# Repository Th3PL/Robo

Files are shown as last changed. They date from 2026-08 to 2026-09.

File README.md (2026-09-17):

# 🤖 Carrinho-Robô SMARS — Bluetooth + desvio de obstáculos

**Project-based Maker Lab · Check Point 1 · FIAP**

| Integrante | RM |
|---|---|
| Fernanda Kaory Saito | RM551104 |
| João Pedro Borsato Cruz | RM550294 |
| Maria Fernanda Vieira de Camargo | RM97956 |
| Pedro Lucas de Andrade Nunes | RM550366 |
| Sofia Amorim Coutinho | RM552534 |

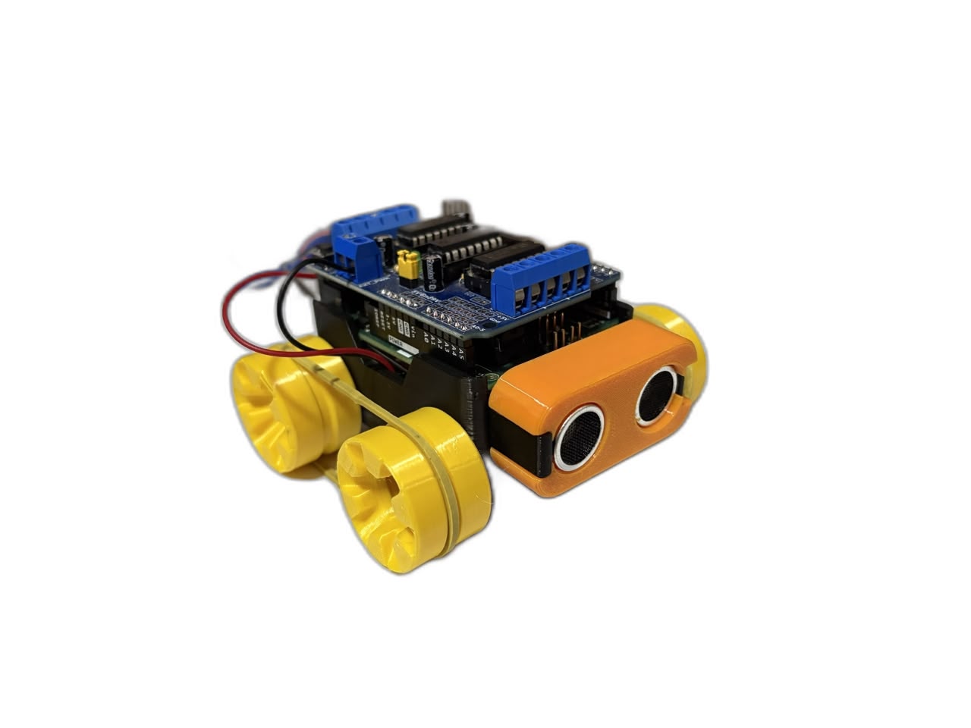
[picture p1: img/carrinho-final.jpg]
Carrinho finalizado


🎬 **Vídeo de funcionamento (controle remoto + sensor + modo autônomo):** https://youtu.be/DnCW8VLloSI

---

## Sumário

1. [Objetivo e descrição](#1-objetivo-e-descrição)
2. [Principais funcionalidades](#2-principais-funcionalidades)
3. [Organização do repositório](#3-organização-do-repositório)
4. [Linha do tempo do projeto](#4-linha-do-tempo-do-projeto)
5. [Requisitos, planejamento e evolução](#5-requisitos-planejamento-e-evolução)
6. [Projeto mecânico e fabricação](#6-projeto-mecânico-e-fabricação)
7. [Hardware e eletrônica](#7-hardware-e-eletrônica)
8. [Software](#8-software)
9. [Testes e resultados](#9-testes-e-resultados)
10. [Evidências finais e instruções de uso](#10-evidências-finais-e-instruções-de-uso)
11. [Custos](#11-custos)
12. [Créditos e licença](#12-créditos-e-licença)

---

## 1. Objetivo e descrição

Desenvolver um carrinho-robô funcional integrando projeto mecânico, fabricação digital, eletrônica,
programação e documentação. O robô é controlado pelo celular via **Bluetooth**, possui um **sensor
ultrassônico** que impede colisões e um **modo autônomo** em que anda sozinho desviando de obstáculos.

A estrutura é impressa em 3D a partir do projeto open-source **SMARS**, montada e adaptada pela equipe:
a proposta original com esteiras foi descartada após os testes e as **rodas foram redesenhadas** pela
equipe em quatro iterações até chegar a uma versão com canal para elástico, que resolveu a tração.

| | |
|---|---|
| **Microcontrolador** | Arduino Uno R3 |
| **Ponte H** | Shield L293D (empilhado no Uno) |
| **Motores** | 2× N20 com redução, 6 V, 500 rpm |
| **Sensor** | HC-SR04 (ultrassônico), na capa frontal |
| **Comunicação** | HC-05 (Bluetooth SPP) + app *Arduino Bluetooth RC Car* |
| **Alimentação** | Bateria 9 V no compartimento do chassi |
| **Estrutura** | Chassi SMARS impresso em PLA · rodas redesenhadas pela equipe |

---

## 2. Principais funcionalidades

- **Controle remoto Bluetooth**: frente, ré, esquerda, direita, diagonais, parar e **velocidade** pelo slider do app.
- **Segurança por sensor**: no modo manual, um obstáculo a menos de 20 cm **bloqueia o avanço** (ré e giros continuam liberados); liberou o caminho, o avanço volta.
- **Modo autônomo** (botão `X` do app): anda sozinho, desacelera ao se aproximar de obstáculos e, ao encontrar um, dá ré e **gira até o sensor ver caminho livre**; se ficar preso, faz manobra de fuga.
- **Leitura robusta do ultrassônico**: timeout, mediana de 3 leituras e tratamento de "sem eco".
- **Tração diferencial** com rodas motoras 1 mm maiores que as livres (contato garantido) e elástico na banda de rodagem.
- **Telemetria** pela USB (distância, modo, comandos) para depuração e calibração.

---

## 3. Organização do repositório

```
Robo/
├── README.md                      ← este documento
├── cad/
│   ├── README.md                  ← origem do chassi, evolução das rodas, como regenerar
│   ├── stl/robo_arduino.3mf       ← projeto de fatiamento completo (9 placas, Sovol SV07)
│   ├── stl/rodas/*.stl            ← rodas v1 (lisa), v2 (ranhurada) e v4 (canal p/ elástico — final)
│   └── scripts/                   ← remodel.js (gera as rodas), manifold_check.js, stl_render.js
├── hardware/
│   ├── conexoes.md                ← pinagem final, diagrama e alimentação
│   └── diagrama-componentes.*     ← diagrama da arquitetura PLANEJADA (L298N), mantido como histórico
├── software/
│   ├── smars_completo/            ← FIRMWARE FINAL: Bluetooth + segurança + modo autônomo
│   ├── smars_bluetooth/           ← só controle Bluetooth (didático)
│   ├── smars_desvio/              ← só desvio autônomo (didático)
│   └── historico/                 ← versões iniciais (v1) mantidas como registro
├── organizacao/                   ← MVP, MoSCoW, Backlog, Kanban (planejamento das aulas)
└── img/
    ├── carrinho-final.jpg · componentes.jpg · chassi-interno.jpg
    ├── previa.png · diagrama-blocos.png · diagrama-eletrico.png · tabela.png   (proposta inicial)
    ├── fabricacao/placa-1..9.png  ← placas de impressão
    └── rodas/                     ← renders de cada versão das rodas
```

---

## 4. Linha do tempo do projeto

| Data | Etapa | Evidência |
|---|---|---|
| **13/08** | Kickoff: repositório criado, definição dos requisitos, levantamento e medição dos componentes | commits `49098f2`, `54a73b1`; [img/tabela.png](img/tabela.png) |
| **18/08** | Proposta inicial: diagrama de blocos, diagrama elétrico (comando/potência) e prévia 3D do carrinho. Arquitetura planejada: Uno + L298N + 2× N20 + HC-SR04 + HC-05 + 7,4 V | commit `8a23aa2`; [previa](img/previa.png), [blocos](img/diagrama-blocos.png), [elétrico](img/diagrama-eletrico.png) |
| **27/08** | Planejamento: MVP, MoSCoW, backlog com 38 tarefas e kanban; projeção de custos | PR #1 `tarefa17-mvp`, commit `2977194`; [organizacao/](organizacao/) |
| **01/09** | Fabricação digital: escolha do chassi SMARS, fatiamento em 9 placas (Bambu Studio, perfil Sovol SV07); diagrama de componentes | commit `f2c2535`; [cad/stl/robo_arduino.3mf](cad/stl/robo_arduino.3mf), [img/fabricacao/](img/fabricacao/) |
| **01/09 – início de set.** | Impressão de todas as peças e montagem. **Decisões**: shield L293D no lugar da L298N; bateria 9 V no lugar de 7,4 V (compartimento do chassi) | [img/componentes.jpg](img/componentes.jpg), [img/chassi-interno.jpg](img/chassi-interno.jpg) |
| **11/09** | Primeiro teste de locomoção com **esteiras**: laço curto demais, a esteira pressionava as rodas e **travava o motor**. Tentativas: compensação XY dos furos no fatiador (0,065 → 0,115 mm), esticar cada elo 1,4 % (16 elos), lixar e lubrificar as juntas. Sem sucesso → **esteiras descartadas** | seção [Testes](#9-testes-e-resultados) |
| **15/09** | **Rodas v1 (lisas Ø32)** geradas por script a partir da roda original: dentes de engate removidos, encaixes internos preservados. **v2 ranhurada** (24 sulcos) para tração | [cad/README.md](cad/README.md), [img/rodas/](img/rodas/) |
| **16/09** | Problema: rodas motoras **girando em falso** (mesmo diâmetro das livres → perdiam contato). **v3**: motoras Ø33, livres Ø32 | `cad/stl/rodas/roda_motor_*.stl` |
| **17/09** | **v4 – canal para elástico** com parede em rampa de 45° (imprime sem suporte). Elástico nas motoras: **tração resolvida** ✅ | [img/rodas/v4-canal-render.png](img/rodas/v4-canal-render.png) |
| **17/09** | Firmware: desvio v1 → v2 (filtro, escaneio) → **v3** (gira até ver livre, fuga); Bluetooth v2 (velocidade, diagonais); **firmware unificado** com modo manual seguro + autônomo | [software/](software/) |
| **17/09** | Documentação final desta versão do repositório | este README |

---

## 5. Requisitos, planejamento e evolução

### 5.1 Requisitos (MVP)

Definidos em [organizacao/MVP.pdf](organizacao/MVP.pdf) e priorizados em [organizacao/MoSCoW .pdf](organizacao/MoSCoW%20.pdf):

| Requisito | Critério de aceite | Status |
|---|---|---|
| Arduino operacional | programa carregado e executando | ✅ |
| Ponte H controla os dois motores | frente, ré e curvas | ✅ (shield L293D) |
| Frente / ré / esquerda / direita / parar | movimentos executados pelo robô | ✅ |
| Bluetooth | celular envia comandos ao Arduino | ✅ |
| HC-SR04 mede distância | leitura correta em cm | ✅ (com filtro) |
| Segurança: obstáculo tem prioridade sobre o avanço | robô impede o avanço | ✅ |
| Alimentação por bateria | opera sem USB | ✅ (9 V) |
| *Should*: velocidade por PWM, distância configurável | slider do app; constantes no código | ✅ |
| *Could*: modo automático com desvio de obstáculos | robô navega sozinho | ✅ |
| *Should*: tratamento de perda do Bluetooth | estado seguro ao perder conexão | ⏳ backlog |

### 5.2 Proposta inicial e esboços

| Prévia 3D (18/08) | Diagrama de blocos planejado |
|---|---|
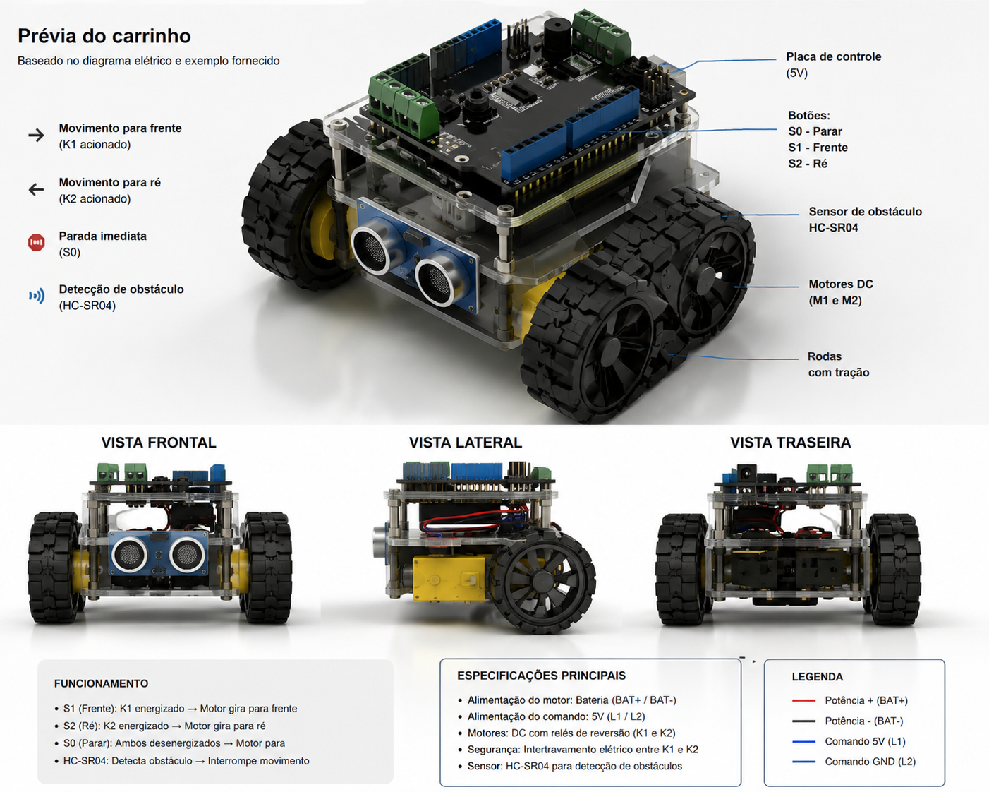
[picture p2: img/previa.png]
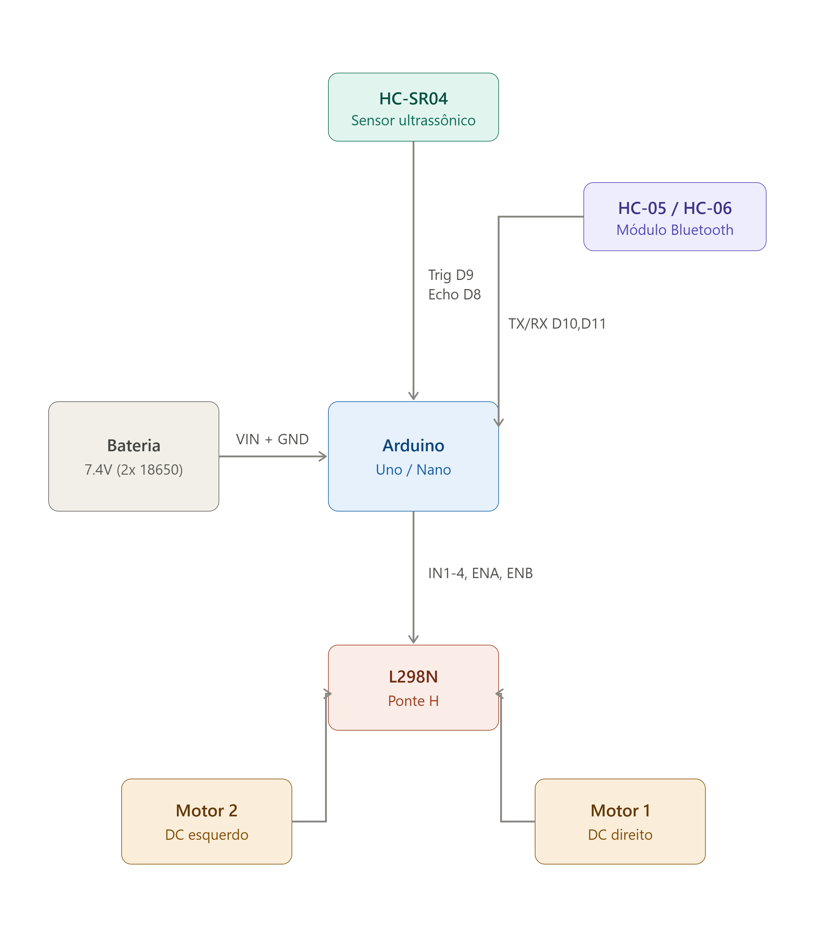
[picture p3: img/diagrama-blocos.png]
|  |  |

Diagrama elétrico da lógica de comando/potência (18/08): [img/diagrama-eletrico.png](img/diagrama-eletrico.png).
Dimensões medidas dos componentes para o projeto do chassi (13/08): [img/tabela.png](img/tabela.png).

### 5.3 Planejamento

- **MVP** — [organizacao/MVP.pdf](organizacao/MVP.pdf): quando o robô é "minimamente funcional" e quando está concluído.
- **MoSCoW** — [organizacao/MoSCoW .pdf](organizacao/MoSCoW%20.pdf): must / should / could / won't.
- **Backlog** — [organizacao/Backlog.md](organizacao/Backlog.md): 38 tarefas com responsável, dependência e critério de aceite.
- **Kanban** — [organizacao/Kanban.md](organizacao/Kanban.md): colunas, limites de WIP e sprints.

### 5.4 Decisões de projeto (planejado × construído)

| Item | Planejado (ago.) | Construído (set.) | Por quê |
|---|---|---|---|
| Ponte H | L298N avulsa, 6 fios de controle | **Shield L293D** empilhado no Uno | Encaixa direto no Uno e no chassi SMARS, elimina jumpers de controle, mais barato (R$ 11,90) |
| Alimentação | 2× 18650 (7,4 V) | **Bateria 9 V alcalina** | O chassi SMARS tem compartimento para 9 V; dispensa carregador/BMS; os 9 V compensam a queda de ~1,5 V do L293D |
| Locomoção | 2 rodas motoras + roda boba | **4 rodas: 2 motoras + 2 livres**, sem esteira | Esteira do SMARS travava o motor; rodas com elástico deram tração e permitem girar no lugar |
| Rodas | rodas do SMARS com dentes de esteira | **Rodas redesenhadas** (v4: lisas, Ø33/Ø32, canal p/ elástico) | Ver [linha do tempo](#4-linha-do-tempo-do-projeto) e [cad/README.md](cad/README.md) |
| Pinos do HC-SR04 | D8 / D9 | **A0 / A1** | D8 e D9 são usados pelo shield |
| Pinos do HC-05 | D10 / D11 | **D9 / D10** (conectores de servo do shield) | D11 é o PWM do motor M1 no shield |
| Sensor no software | só parada por obstáculo | Parada **+ desvio autônomo + fuga quando preso** | Evolução de item *could have* do MoSCoW |

### 5.5 Status final do backlog

| Tarefas | Status |
|---|---|
| T01–T10 componentes, layout, base, fixações | ✅ concluídas (chassi SMARS impresso; suportes de motor, bateria e sensor) |
| T11–T13 alimentação e ligação dos motores | ✅ (bateria 9 V → shield; motores em M1/M2) |
| T14–T20 testes dos motores e funções de movimento | ✅ |
| T21–T23 sensor conectado, leitura, parada por obstáculo | ✅ |
| T24–T26 Bluetooth e mapeamento de comandos | ✅ |
| T27 fail-safe de perda do Bluetooth | ⏳ não implementado |
| T28 calibração da distância | ✅ (constantes `DIST_PARAR`, `DIST_REDUZIR`, `DIST_LIVRE`) |
| T29–T30 movimentação integrada e detecção em movimento | ✅ |
| T31 organização dos cabos | 🔶 parcial |
| T32 autonomia da bateria | ⏳ não medida formalmente |
| T33–T34 percurso completo e correção de bugs | ✅ (ver [Testes](#9-testes-e-resultados)) |
| T35–T37 documentação de circuito, software e montagem | ✅ |
| T38 demonstração | 🎬 vídeo — link no topo |

---

## 6. Projeto mecânico e fabricação

### 6.1 Chassi

O chassi é o **SMARS** (Screwless Modular Assemblable Robotic System, de Kevin Thomas — projeto open-source
publicado no Thingiverse sob licença Creative Commons). Foi escolhido em 01/09 porque já prevê exatamente os
componentes do nosso planejamento: berços para motores N20, compartimento para bateria 9 V, encaixe do Arduino
Uno com shield e capa frontal para o HC-SR04. Toda a fabricação (fatiamento, impressão, pós-processamento e
montagem) foi feita pela equipe; a **adaptação mecânica** foi o redesenho completo das rodas.

**Fatiamento** — Bambu Studio 2.3, perfil Sovol SV07, bico 0,4 mm, camada 0,2 mm, PLA. Projeto completo em
[cad/stl/robo_arduino.3mf](cad/stl/robo_arduino.3mf), organizado em 9 placas:

| Placa 1 – esteiras | Placa 2 – chassi | Placa 3 – rodas originais |
|---|---|---|
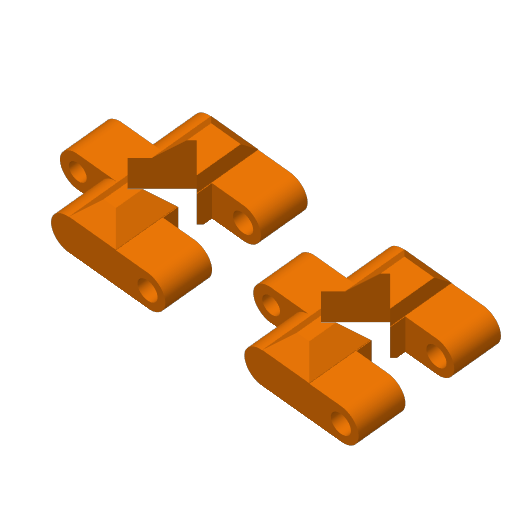
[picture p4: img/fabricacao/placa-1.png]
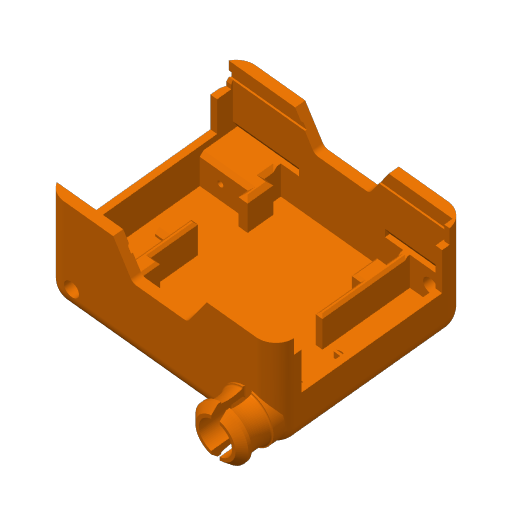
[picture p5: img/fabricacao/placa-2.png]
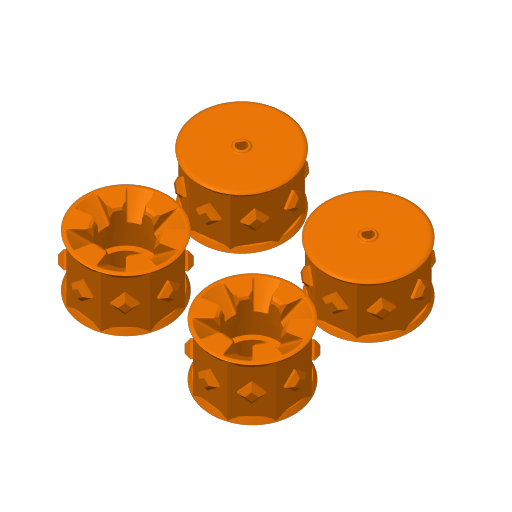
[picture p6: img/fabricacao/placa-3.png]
|  |  |  |
| **Placa 4 – suporte bateria 9 V** | **Placa 5 – suporte sensor IR (opcional)** | **Placa 6 – conector (opcional)** |
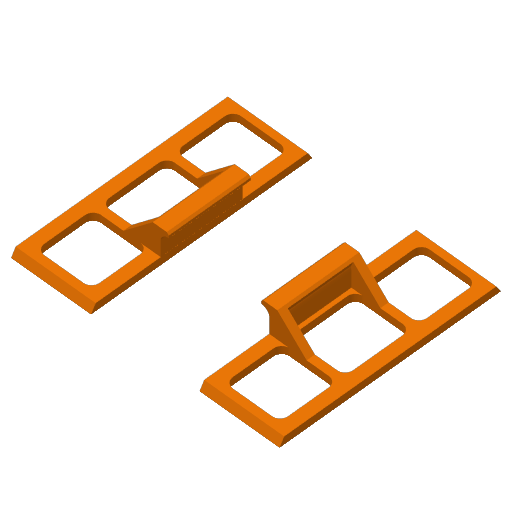
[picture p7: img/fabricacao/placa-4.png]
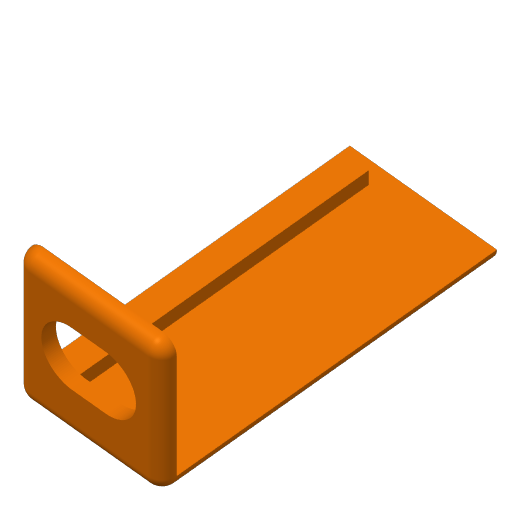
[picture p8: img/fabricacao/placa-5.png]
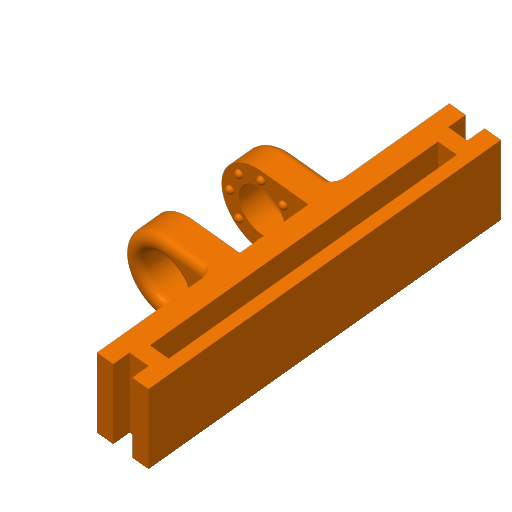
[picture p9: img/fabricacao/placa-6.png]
|  |  |  |
| **Placa 7 – capa HC-SR04 (base)** | **Placa 8 – capa HC-SR04 (a)** | **Placa 9 – capa HC-SR04 (b)** |
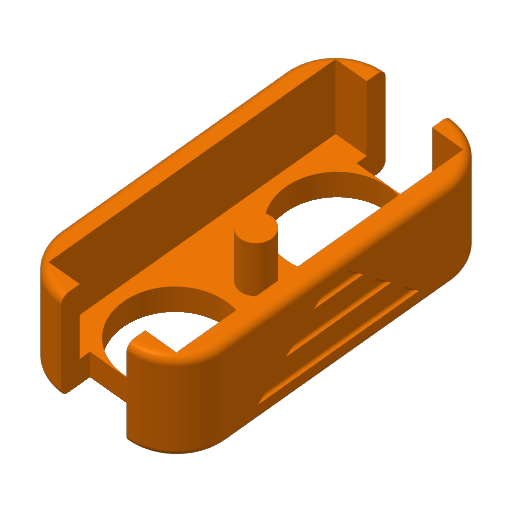
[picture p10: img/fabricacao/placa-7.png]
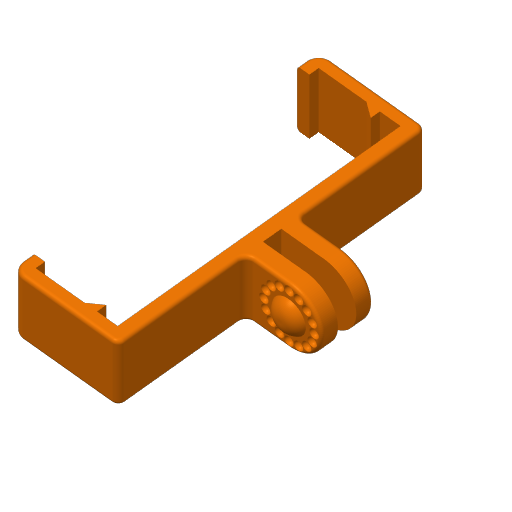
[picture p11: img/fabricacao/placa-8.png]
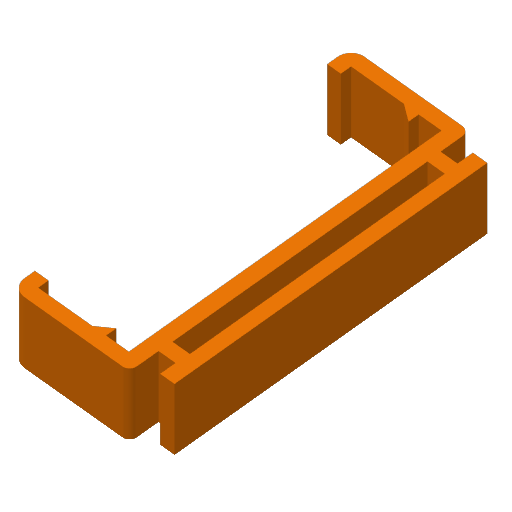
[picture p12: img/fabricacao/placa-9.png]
|  |  |  |

| Peças impressas antes da montagem | Chassi montado por baixo (motores N20 nos berços, bateria 9 V) |
|---|---|
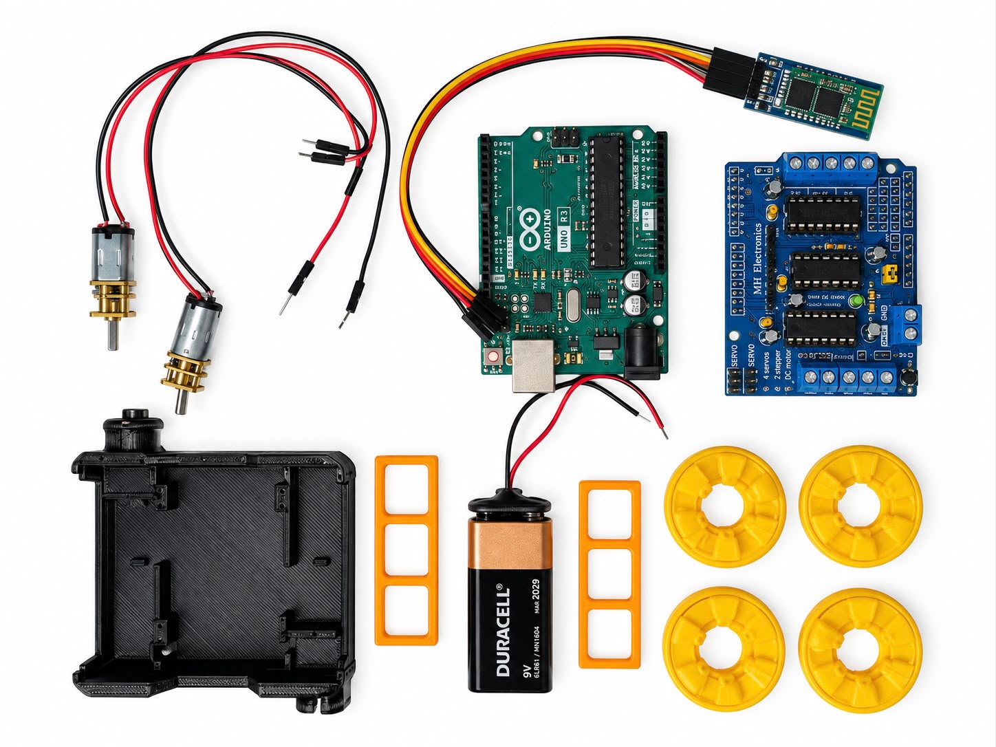
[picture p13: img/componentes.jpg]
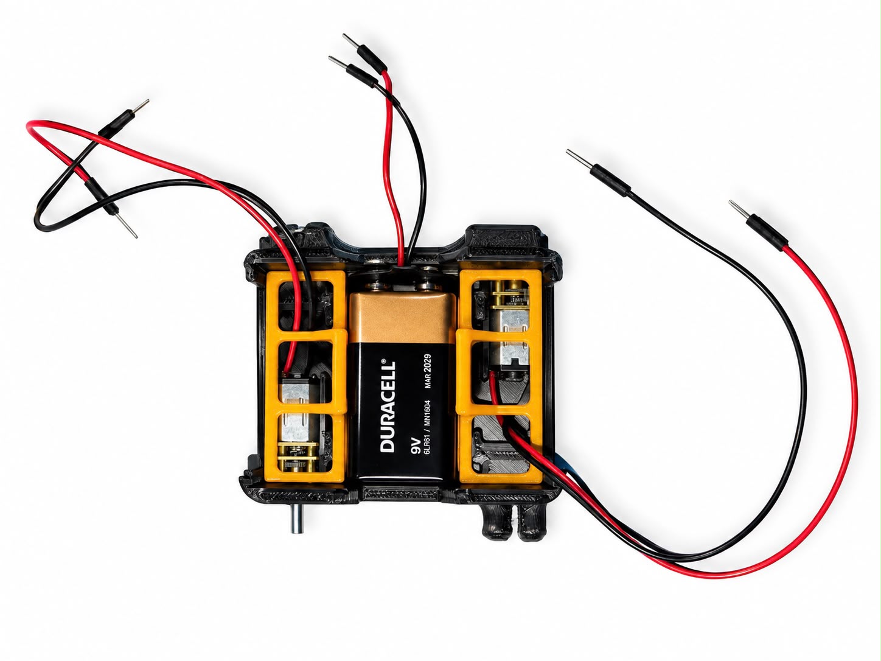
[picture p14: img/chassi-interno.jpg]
|  |  |

### 6.2 Rodas — quatro iterações

A roda original do SMARS tem 8 dentes piramidais que engatam nos losangos da esteira. Como a esteira foi
descartada, as rodas foram **regeneradas por script** ([cad/scripts/remodel.js](cad/scripts/remodel.js)) a
partir do STL original: a superfície externa é reconstruída (lisa, ranhurada ou com canal) enquanto o
**encaixe interno** (furo D do motor N20, cavidade de 6 lóbulos, furo passante da roda livre) é preservado.
Cada STL foi validado por um verificador de malha (0 arestas abertas, 0 não-manifold) antes de imprimir.

| v0 – original (dentes p/ esteira) | v1 – lisa Ø32 | v2 – ranhurada |
|---|---|---|
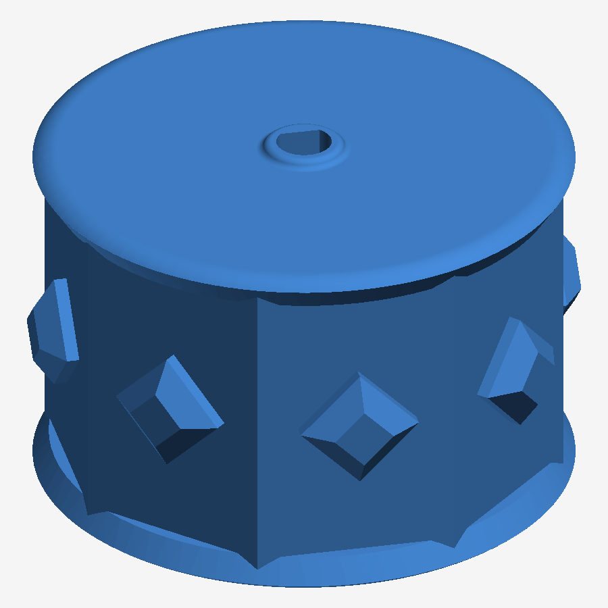
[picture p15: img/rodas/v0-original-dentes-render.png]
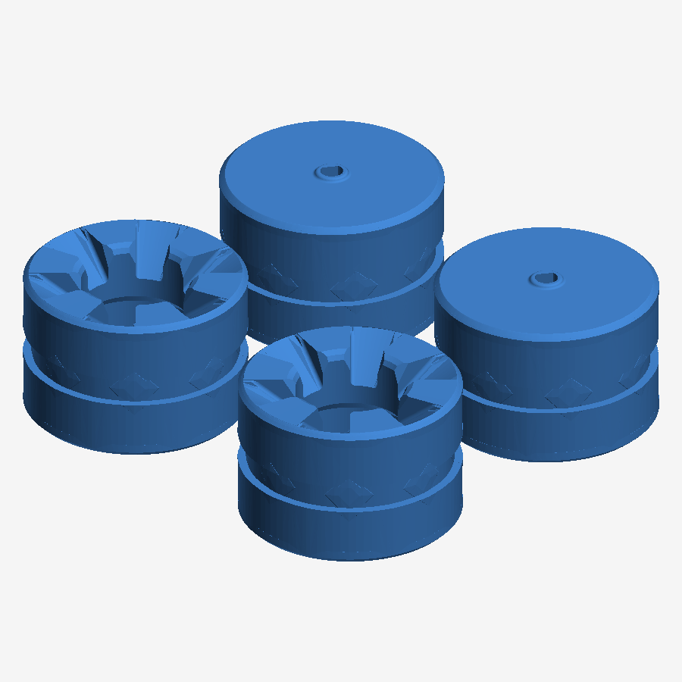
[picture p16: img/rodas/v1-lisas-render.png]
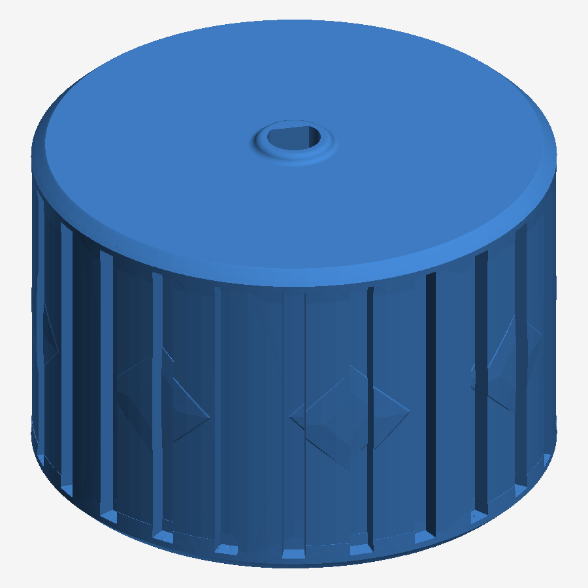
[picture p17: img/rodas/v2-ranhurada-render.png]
|  |  |  |
| **Elo da esteira descartada** | **v4 – canal para elástico (final)** | **v4 – perfil do canal** |
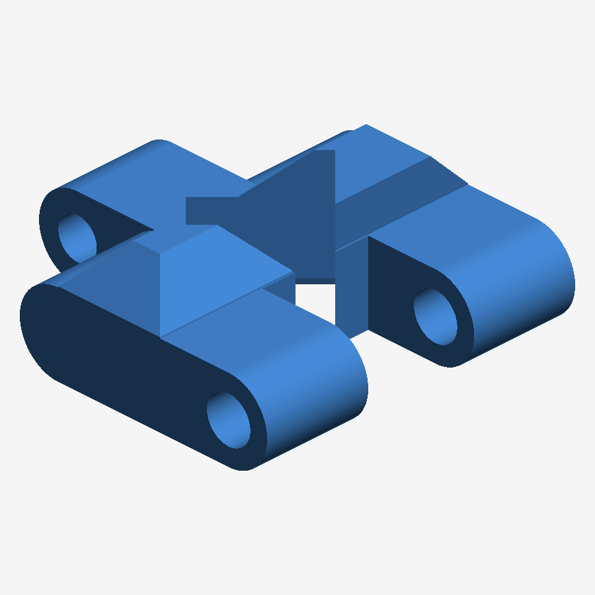
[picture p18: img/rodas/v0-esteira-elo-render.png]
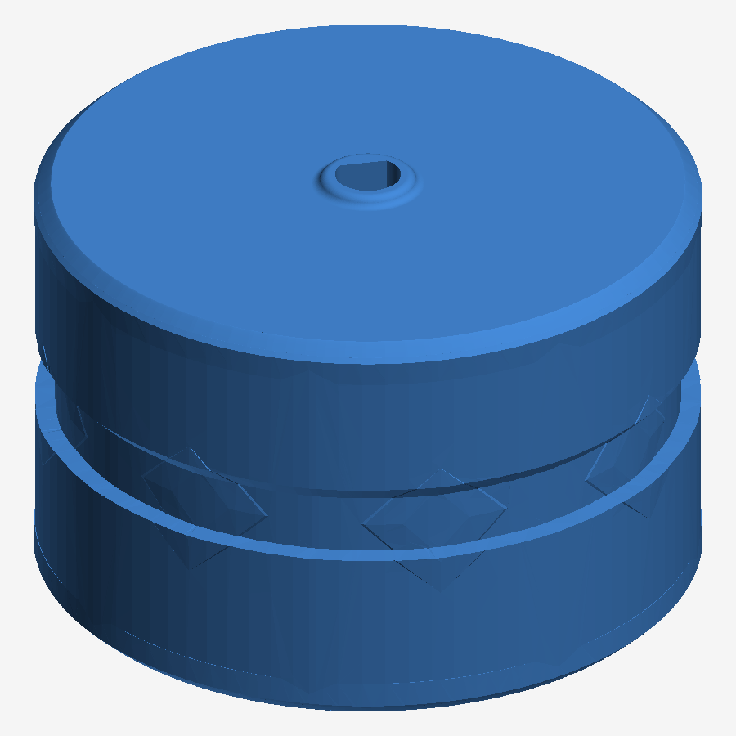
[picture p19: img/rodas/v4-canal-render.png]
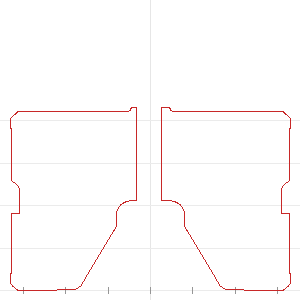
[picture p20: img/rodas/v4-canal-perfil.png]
|  |  |  |

Decisões de detalhe da v4:
- **Motora Ø33 × livre Ø32**: com 4 rodas rígidas, diâmetros iguais deixam uma roda no ar (como mesa de 4 pés). A motora 0,5 mm mais alta garante que o carrinho sempre apoie nas rodas de tração.
- **Canal** com fundo plano de 3 mm, 1 mm de profundidade, parede inferior reta e **parede superior em rampa de 45°**: imprime deitado sem suporte.
- **Elástico só nas motoras**: as rodas livres precisam deslizar de lado para o carrinho girar no lugar.
- Chanfros de 0,8 mm nas bordas; residual dos dentes reduzido a < 0,1 mm (abaixo da resolução do bico).

Tabela completa das versões, arquivos e como regenerar: [cad/README.md](cad/README.md).

### 6.3 Carenagem e acabamento

- **Capa frontal do sensor** (peças `ultrasonic_1`, `ultrasonic_2a`, `ultrasonic_2b` — placas 7 a 9), impressa em laranja: protege e posiciona o HC-SR04 voltado para a frente, com os dois transdutores expostos.
- **Suportes internos** da bateria (laranja) e dos motores integrados ao chassi; bateria e motores ficam totalmente encapsulados, com o shield acessível por cima para programação e troca de bateria.
- **Acesso aos componentes**: a parte superior (Uno + shield) fica aberta, o que permite programar pelo USB, trocar a bateria e mexer nos bornes sem desmontar nada. Uma tampa superior encaixável está prevista como melhoria (backlog).

---

## 7. Hardware e eletrônica

### 7.1 Lista de componentes

| Componente | Qtd | Função |
|---|---|---|
| Arduino Uno R3 | 1 | Microcontrolador: lógica, leitura do sensor, comunicação |
| Shield de motores L293D (MH Electronics, compatível Adafruit v1) | 1 | Ponte H de 4 canais (usamos M1 e M2) e distribuição de energia |
| Motor N20 com redução, 6 V, 500 rpm | 2 | Tração das rodas motoras |
| Sensor ultrassônico HC-SR04 | 1 | Distância 2–400 cm, detecção de obstáculos |
| Módulo Bluetooth HC-05 | 1 | Recebe comandos do celular (SPP, 9600 bps) |
| Bateria 9 V alcalina (6LR61) | 1 | Alimenta shield, motores e Uno |
| Chassi SMARS + suportes + capa do sensor (PLA) | — | Estrutura |
| Rodas redesenhadas v4 (PLA) | 4 | 2 motoras Ø33, 2 livres Ø32 |
| Elástico de dinheiro | 2 | Banda de rodagem das motoras (2 voltas cada) |
| Jumpers macho-macho e macho-fêmea | ~10 | Sensor, Bluetooth, bateria |

### 7.2 Diagrama de conexões

```mermaid
flowchart LR
    APP["Celular<br/>app Bluetooth RC Car"]
    BT["HC-05"]
    US["HC-SR04"]
    BAT["Bateria 9 V"]
    subgraph UNO["Arduino Uno R3 + shield L293D"]
        FW["Firmware"]
        H["Ponte H L293D"]
        FW -- "sentido + PWM" --> H
    end
    ME["Motor N20 esq."]
    MD["Motor N20 dir."]
    APP <-- "Bluetooth" --> BT
    BT <-- "D9 RX / D10 TX" --> FW
    US -- "TRIG A0 / ECHO A1" --> FW
    H -- "M1" --> ME
    H -- "M2" --> MD
    BAT -- "EXT_PWR" --> UNO
```

Tabela de ligações pino a pino, pinos reservados pelo shield e notas de alimentação:
**[hardware/conexoes.md](hardware/conexoes.md)**. O diagrama da arquitetura planejada (L298N) está em
[hardware/diagrama-componentes.png](hardware/diagrama-componentes.png).

### 7.3 Alimentação

Bateria 9 V no borne EXT_PWR do shield, jumper PWR instalado (o shield alimenta o Uno pelo Vin). O L293D
derruba ~1,5 V, então os motores recebem ~7,5 V. Com uma fonte menor (4 pilhas AA, 6 V) os motores ficariam
com ~4,5 V — insuficiente para vencer o atrito lateral das rodas livres nos giros no lugar.

### 7.4 Fotos da montagem

[img/componentes.jpg](img/componentes.jpg) · [img/chassi-interno.jpg](img/chassi-interno.jpg) · [img/carrinho-final.jpg](img/carrinho-final.jpg)

---

## 8. Software

### 8.1 Sketches

| Pasta | Uso | Estado |
|---|---|---|
| [`software/smars_completo/`](software/smars_completo/smars_completo.ino) | **Firmware final** — controle Bluetooth com segurança por sensor + modo autônomo, em um único upload | ✅ usar este |
| [`software/smars_bluetooth/`](software/smars_bluetooth/smars_bluetooth.ino) | Só controle Bluetooth (versão didática, sem sensor) | ✅ |
| [`software/smars_desvio/`](software/smars_desvio/smars_desvio.ino) | Só navegação autônoma (versão didática) | ✅ |
| [`software/historico/`](software/historico/) | Versões iniciais v1, com os problemas anotados no cabeçalho | histórico |

Compilação: Arduino IDE 2.x, placa **Arduino Uno**, biblioteca **Adafruit Motor Shield library (v1)**
(`AFMotor.h`). Os três sketches compilam sem avisos (≈ 6,4 kB de flash, 338 B de RAM no completo).

### 8.2 Como o programa funciona (`smars_completo`)

**Controle dos motores.** A biblioteca `AFMotor` comanda o shield: o sentido de cada canal passa por um
registrador 74HC595 e a velocidade pelos pinos PWM D11 (M1) e D3 (M2). A função `aplicar(velE, velD, dirE, dirD)`
centraliza tudo; `VEL_MAX_E/D` permitem compensar um motor mais forte para o carrinho andar reto. Curvas são
feitas por **tração diferencial**: giro no lugar (uma roda para frente, outra para trás) e diagonais com a roda
de dentro a 35 %.

**Comunicação sem fio.** O HC-05 conversa com o Uno por `SoftwareSerial` nos pinos D9/D10 a 9600 bps. O app
*Arduino Bluetooth RC Car* envia um caractere por botão:

| Caractere | Ação | | Caractere | Ação |
|---|---|---|---|---|
| `F` `B` | frente / ré | | `G` `I` | frente-esquerda / frente-direita |
| `L` `R` | gira esquerda / direita | | `H` `J` | ré-esquerda / ré-direita |
| `S` | parar (sai do autônomo) | | `0`–`9`, `q` | velocidade 10 %…100 % |
| `X` | **liga modo autônomo** | | `x` | desliga modo autônomo |

O último comando fica guardado e é reaplicado a cada volta do `loop()`, o que permite o bloqueio de segurança
descrito abaixo sem perder o comando do usuário.

**Sensor ultrassônico.** `lerCrua()` dispara o TRIG (10 µs) e mede o ECHO com `pulseIn` **com timeout de
25 ms** (sem eco = 400 cm, "livre" — a versão inicial devolvia 0 e o robô dava ré sem motivo). Um ping a
cada 60 ms e a **mediana das 3 últimas leituras** eliminam picos falsos sem travar o loop.

**Segurança (modo manual).** Se o último comando é de avanço (`F`, `G`, `I`) e a distância ≤ `DIST_PARAR`
(20 cm), os motores param; ré e giros continuam liberados. Quando o caminho libera, o avanço é retomado. Isso
implementa o requisito do MVP "obstáculo tem prioridade sobre o comando de avanço".

**Modo autônomo.** `passoAutonomo()` anda a `VEL_CRUZEIRO` e desacelera linearmente entre 45 e 20 cm. Ao
detectar obstáculo, `desviar()`: dá ré → **gira até o sensor ver ≥ 40 cm em 3 leituras seguidas** (+ margem)
→ segue. Se não abrir em 2,5 s: ré em arco para o outro lado e tenta o outro lado; se ainda não abrir:
meia-volta. Batidas seguidas mantêm o mesmo lado (a parede está do lado oposto); 3 desvios em 6 s = preso →
ré em arco longa e troca de lado. Girar "até ver livre" (em vez de girar por tempo fixo) foi a mudança que
resolveu o robô ficar oscilando frente-ré diante de paredes.

**Calibração.** Todas as constantes estão no topo do sketch: distâncias (`DIST_*`), velocidades (`VEL_*`),
tempos de manobra (`T_*`) e compensação por motor (`VEL_MAX_E/D`). O monitor serial (9600 bps) mostra o modo,
a distância e cada decisão de manobra.

### 8.3 Evolução do software

| Versão | Problema encontrado | Correção |
|---|---|---|
| v1 desvio ([historico](software/historico/v1_desvio_obstaculo.ino)) | `pulseIn` sem timeout → leituras 0 cm → ré aleatória; `int` estourava; reagia só a 7 cm; virava 500 ms às cegas | — |
| v2 desvio | filtro de mediana, reação a 20 cm, escaneio girando 45° para cada lado por tempo fixo | Ainda travava em paredes: quando o giro cronometrado ficava curto, media a mesma parede dos dois lados |
| **v3 desvio** ([smars_desvio](software/smars_desvio/smars_desvio.ino)) | — | Gira **até o sensor ver livre**, ré em arco, meia-volta, detecção de "preso", memória de lado |
| v1 Bluetooth ([historico](software/historico/v1_bluetooth.ino)) | `read()` sem `available()`; velocidade fixa; `J` tratado como parar | — |
| **v2 Bluetooth** ([smars_bluetooth](software/smars_bluetooth/smars_bluetooth.ino)) | — | slider de velocidade, diagonais, compensação por motor, 255 |
| **Unificado** ([smars_completo](software/smars_completo/smars_completo.ino)) | dois uploads diferentes para demonstrar sensor e Bluetooth | manual seguro + autônomo no mesmo firmware, alternado pelo app |

---

## 9. Testes e resultados

| # | Teste | Resultado | Problema / correção |
|---|---|---|---|
| 1 | Motores individuais (frente/ré) pelo shield | ✅ | — |
| 2 | Comandos Bluetooth F/B/L/R/S pelo app | ✅ | — |
| 3 | Locomoção com **esteiras** | ❌ | Laço curto: esteira pressionava as rodas e travava o motor. Tentativas: compensação de furos no fatiador +0,05 mm, elos esticados 1,4 %, lixa e lubrificação → **esteiras descartadas** |
| 4 | Rodas v1 lisas | ❌ | Rodam, mas PLA liso patina no piso |
| 5 | Rodas v2 ranhuradas (Ø32 = Ø32) | ❌ | Motoras giravam em falso: com diâmetros iguais perdiam o contato com o chão |
| 6 | Rodas v3 (motora Ø33 > livre Ø32) | 🔶 | Contato garantido; ainda faltava atrito em piso liso |
| 7 | Rodas v4 + elástico nas motoras | ✅ | **Tração resolvida**; carrinho anda e gira no lugar |
| 8 | Força dos motores | ✅ | Software já no máximo (`setSpeed(255)`); a força é definida pela tensão no shield (9 V) — ver [hardware/conexoes.md](hardware/conexoes.md) |
| 9 | Sensor: leituras com `pulseIn` sem timeout | ❌ | Valores 0 cm → ré aleatória. Corrigido com timeout + mediana |
| 10 | Desvio v2 diante de parede | ❌ | Oscilava frente-ré (giro cronometrado insuficiente) |
| 11 | Desvio v3 / firmware unificado | 🔄 | Gira até ver caminho livre; validação final registrada no vídeo |
| 12 | Bloqueio de avanço no modo manual | 🔄 | Obstáculo a < 20 cm para o carrinho; validação no vídeo |
| 13 | Autonomia da bateria | ⏳ | Não medida formalmente |

**Resultado final:** carrinho funcional, controlado pelo celular, com bloqueio de colisão e modo autônomo;
estrutura impressa em 3D com rodas redesenhadas pela equipe após o descarte das esteiras.

---

## 10. Evidências finais e instruções de uso

- **Foto do carrinho finalizado:** [img/carrinho-final.jpg](img/carrinho-final.jpg)
- **Vídeo (controle remoto, sensor e modo autônomo):** https://youtu.be/DnCW8VLloSI

### Como usar

1. Coloque a bateria 9 V no compartimento e conecte-a ao borne EXT_PWR do shield. O LED do HC-05 pisca rápido (aguardando pareamento).
2. No celular, pareie com o **HC-05** (PIN `1234` ou `0000`).
3. Abra o app **Arduino Bluetooth RC Car** (Android) → ícone de engrenagem → *Connect to car* → HC-05.
4. Setas: frente, ré, esquerda, direita e diagonais. Slider: velocidade. Ao soltar o botão o carrinho para.
5. Com um obstáculo a menos de 20 cm o avanço é bloqueado automaticamente; ré e giros continuam funcionando.
6. Botão extra **X** (ligado) → **modo autônomo**; **X** (desligado), qualquer seta ou *stop* → volta ao manual.
7. Para reprogramar: retire o jumper PWR do shield (ou a bateria), conecte o USB, grave `software/smars_completo` com a IDE Arduino (placa *Arduino Uno*, biblioteca *Adafruit Motor Shield library*).

Calibração recomendada no piso da demonstração: `VEL_MAX_E/D` (andar reto) e `T_MEIA_VOLTA_MS` (tempo de 180°).

---

## 11. Custos

| Componente | Qtd | Unitário | Total |
|---|---|---|---|
| Motor N20 500 rpm | 2 | R$ 20,40 | R$ 40,80 |
| Arduino Uno R3 | 1 | R$ 100,07 | R$ 100,07 |
| Módulo Bluetooth HC-05 | 1 | R$ 12,90 | R$ 12,90 |
| Shield ponte H L293D | 1 | R$ 11,90 | R$ 11,90 |
| Sensor HC-SR04 | 1 | R$ 15,00 | R$ 15,00 |
| Bateria 9 V | 1 | R$ 35,00 | R$ 35,00 |
| Cabos e jumpers | — | — | R$ 5,00 |
| Filamento PLA (~150 g) | — | — | R$ 10,00 |
| Elásticos | 2 | — | R$ 0,00 |
| **Total** | | | **R$ 230,67** |

---

## 12. Créditos e licença

- Chassi, suportes e capa do sensor: **SMARS** — Kevin Thomas, Thingiverse, licença Creative Commons (uso não comercial, atribuição).
- Rodas v1–v4, scripts de geração/validação, firmware e documentação: equipe do projeto.
- Biblioteca `AFMotor`: Adafruit Motor Shield library v1 (BSD).
- App de controle: *Arduino Bluetooth RC Car* (Android).

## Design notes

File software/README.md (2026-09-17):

# Software

| Pasta | Conteúdo |
|---|---|
| `smars_completo/` | **Firmware final** — controle Bluetooth com bloqueio de avanço por obstáculo + modo autônomo (`X` liga / `x` desliga) |
| `smars_bluetooth/` | Só controle Bluetooth (versão didática) |
| `smars_desvio/` | Só navegação autônoma com desvio de obstáculos (versão didática, v3) |
| `historico/` | Versões iniciais (v1) do Bluetooth e do desvio, com os problemas anotados no cabeçalho |

## Compilar e gravar

1. Arduino IDE 2.x → *Library Manager* → instalar **Adafruit Motor Shield library** (v1, `AFMotor.h`).
2. Placa: **Arduino Uno**. Abra a pasta do sketch (ex.: `smars_completo/smars_completo.ino`).
3. Antes de conectar o USB, retire o jumper PWR do shield ou a bateria.
4. Upload. Monitor serial a **9600 bps** (`smars_completo`, `smars_bluetooth`) ou **115200** (`smars_desvio`).

Os três sketches compilam sem erros nem avisos (`arduino-cli compile --fqbn arduino:avr:uno --warnings all`).

## Constantes de calibração (topo de cada sketch)

| Constante | Padrão | O que faz |
|---|---|---|
| `VEL_MAX_E`, `VEL_MAX_D` | 255 | Teto de cada motor; abaixe o mais forte se o carrinho puxa para um lado |
| `DIST_PARAR` | 20 cm | Obstáculo: bloqueia avanço (manual) / desvia (autônomo) |
| `DIST_REDUZIR` | 45 cm | Início da desaceleração no autônomo |
| `DIST_LIVRE` | 40 cm | Distância para considerar uma direção livre ao girar |
| `T_MEIA_VOLTA_MS` | 1200 ms | Tempo de giro de ~180° (último recurso) — calibrar no piso |
| `VEL_CRUZEIRO`, `VEL_MINIMA` | 220, 130 | Velocidades do modo autônomo |

A explicação completa do funcionamento está no README principal, seção 8.

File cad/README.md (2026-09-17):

# CAD e fabricação

## Origem do chassi

O chassi é baseado no projeto open-source **SMARS** (Screwless Modular Assemblable Robotic System), de
Kevin Thomas, publicado no Thingiverse sob licença Creative Commons. Escolhemos o SMARS porque o conjunto
já prevê o berço dos motores N20, o compartimento da bateria 9 V e a capa do sensor HC-SR04 — exatamente
os componentes definidos no nosso planejamento. Todas as peças foram fatiadas e impressas pela equipe;
as **rodas foram redesenhadas** pela equipe (ver abaixo), pois a proposta original com esteiras foi descartada.

## Arquivos

| Arquivo | O que é |
|---|---|
| `stl/robo_arduino.3mf` | Projeto de fatiamento completo (Bambu Studio 2.3, perfil Sovol SV07, camada 0,2 mm) com **9 placas**: esteiras, chassi, rodas originais, suporte da bateria 9 V, suporte de sensor IR, conector, capa do HC-SR04 (3 peças) |
| `stl/rodas/roda_motor_canal.stl` | **Versão final** – roda motora Ø33 mm com canal para elástico, autossustentável |
| `stl/rodas/roda_livre_canal.stl` | Versão final – roda livre Ø32 mm com canal |
| `stl/rodas/roda_motor_lisa.stl`, `roda_livre_lisa.stl` | v1/v3 – rodas lisas |
| `stl/rodas/roda_motor_ranhurada.stl`, `roda_livre_ranhurada.stl` | v2 – 24 ranhuras transversais |
| `scripts/remodel.js` | Script (Node.js, sem dependências) que gera as rodas a partir da roda original do SMARS: remove os dentes de engate da esteira e reconstrói a banda de rodagem (lisa / ranhurada / com canal) preservando o encaixe interno do motor e do eixo |
| `scripts/manifold_check.js` | Verificador de malha (arestas abertas / não-manifold) usado para validar cada STL antes de imprimir |
| `scripts/stl_render.js`, `scripts/split_wheels.js` | Render PNG dos STLs e separação das rodas em arquivos individuais |

Placas de impressão (miniaturas geradas pelo fatiador): `../img/fabricacao/placa-1.png` … `placa-9.png`.

## Evolução das rodas

| Versão | Arquivo | Diâmetro motora / livre | Resultado |
|---|---|---|---|
| v0 – original SMARS | no 3MF (`master_wheel`, `slave_wheel_SL`) | Ø32,7 com 8 dentes | Só funciona com esteira. A esteira travava o motor → descartada |
| v1 – lisa | `roda_*_lisa.stl` | Ø32 / Ø32 | Roda livre, mas PLA liso patina no piso |
| v2 – ranhurada | `roda_*_ranhurada.stl` | Ø32 / Ø32 | 24 ranhuras; ainda girava em falso: com diâmetros iguais as motoras ficavam sem contato com o chão |
| v3 – motora maior | (aplicado a v1 e v2; arquivos do repo já estão assim) | **Ø33 / Ø32** | Motora 0,5 mm mais alta garante contato sempre; faltava atrito |
| **v4 – canal para elástico** | `roda_*_canal.stl` | Ø33 / Ø32 (+ elástico) | **Final.** Elástico de dinheiro (2 voltas) nas motoras; tração resolvida |

Detalhes de cada decisão estão na linha do tempo do README principal.

## Como regenerar as rodas

```bash
node scripts/remodel.js roda.stl rodas_canal.stl canal        # variantes: (vazio)=lisa | ranhura | canal
node scripts/split_wheels.js rodas_canal.stl roda_motor_canal.stl roda_livre_canal.stl
node scripts/manifold_check.js roda_motor_canal.stl
```

`roda.stl` é a exportação das 4 rodas originais do 3MF (placa 3). Parâmetros (diâmetros, profundidade do
canal, número de ranhuras) estão no topo de `remodel.js`.

## Impressão

- Impressora Sovol SV07, bico 0,4 mm, camada 0,2 mm, PLA.
- Rodas: imprimir **deitadas, como o arquivo abre** (cavidade do motor para baixo). O canal do elástico tem a
  parede superior em rampa de 45° justamente para não precisar de suporte nessa orientação.
- Elástico: só nas rodas motoras. As rodas livres precisam deslizar de lado para o carrinho girar no lugar.

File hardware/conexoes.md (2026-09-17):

# Conexões elétricas — versão final

Arquitetura construída: Arduino Uno R3 + shield de motores L293D (empilhado no Uno) + 2 motores N20 +
HC-SR04 + HC-05 + bateria 9 V. O shield é a ponte H e também distribui a alimentação: a bateria entra no
borne **EXT_PWR** do shield e o Uno é alimentado pelo próprio shield (jumper PWR instalado).

> Esta é a arquitetura final. O planejamento inicial (`diagrama-componentes.*`, `img/diagrama-blocos.png`)
> previa ponte H L298N avulsa e bateria de 7,4 V; ver "Decisões de projeto" no README.

## Diagrama

```mermaid
flowchart LR
    APP["Celular<br/>app Bluetooth RC Car"]
    BT["HC-05<br/>Bluetooth SPP"]
    US["HC-SR04<br/>ultrassônico"]
    BAT["Bateria 9 V<br/>(6LR61)"]

    subgraph UNO["Arduino Uno R3 + shield L293D"]
        FW["Firmware<br/>software/smars_completo"]
        H["Ponte H L293D<br/>canais M1 e M2"]
        FW -- "PWM + sentido<br/>(74HC595 + D3/D11)" --> H
    end

    ME["Motor N20<br/>esquerdo"]
    MD["Motor N20<br/>direito"]

    APP <-- "2,4 GHz" --> BT
    BT <-- "UART 9600 bps<br/>D9 (RX) / D10 (TX)" --> FW
    US -- "TRIG A0 · ECHO A1" --> FW
    H -- "M1" --> ME
    H -- "M2" --> MD
    BAT -- "EXT_PWR (+/−)" --> UNO
```

## Tabela de ligações

| De | Para | Observação |
|---|---|---|
| Bateria 9 V (+) | Shield **EXT_PWR +** | Jumper **PWR** instalado: o shield alimenta o Uno pelo Vin |
| Bateria 9 V (−) | Shield **EXT_PWR −** (GND) | GND comum de todo o sistema |
| Motor N20 esquerdo | Shield borne **M1** | Inverter os dois fios se o motor girar ao contrário |
| Motor N20 direito | Shield borne **M2** | idem |
| HC-SR04 VCC | 5 V do shield | |
| HC-SR04 GND | GND | |
| HC-SR04 TRIG | **A0** | pinos analógicos usados como digitais (livres no shield) |
| HC-SR04 ECHO | **A1** | |
| HC-05 VCC | 5 V (pino central do conector de servo) | |
| HC-05 GND | GND (conector de servo) | |
| HC-05 TXD | **D9** (sinal do conector SERVO_2) | `SoftwareSerial bt(9, 10)` → RX do Arduino |
| HC-05 RXD | **D10** (sinal do conector SERVO_1) | TX do Arduino |

## Pinos consumidos pelo shield L293D (não usar para outra coisa)

| Pino | Função no shield |
|---|---|
| D3, D11 | PWM dos canais M2 e M1 |
| D4, D7, D8, D12 | registrador 74HC595 (sentido dos motores) |
| D5, D6 | PWM dos canais M3/M4 (não usados) |
| D9, D10 | conectores de servo — reaproveitados para o HC-05 |
| D0, D1 | serial USB (upload e monitor) |

Livres: **A0–A5** (por isso o HC-SR04 está em A0/A1) e D2, D13.

## Alimentação

- Tensão nos motores = 9 V − queda do L293D (~1,4 a 2 V) ≈ **7 a 7,5 V**. Os N20 usados são de 6 V;
  em uso intermitente e com carga leve funcionam bem nessa tensão.
- O Uno recebe 9 V no Vin pelo jumper PWR e regula para 5 V internamente.
- Nunca alimentar o shield pelo USB e pela bateria ao mesmo tempo com o jumper PWR instalado durante testes
  de motor: para programar com a bateria ligada, retire o jumper.

## Fotos da montagem

- `../img/componentes.jpg` — todos os componentes antes da montagem
- `../img/chassi-interno.jpg` — motores N20 nos berços, bateria 9 V central e cabos passando pelo chassi
- `../img/carrinho-final.jpg` — montagem final com shield empilhado e capa do sensor

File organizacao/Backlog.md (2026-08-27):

# Backlog do Projeto – Robô Móvel

## Papéis considerados
Como os nomes da equipe não foram informados, foram definidos quatro responsáveis genéricos:

- **Integrante A:** Software / Arduino
- **Integrante B:** Eletrônica
- **Integrante C:** Mecânica / Estrutura
- **Integrante D:** Testes / Documentação

## Backlog

| ID | Tarefa | Responsável | Prioridade | Dependência | Critério de aceite |
|---|---|---|---|---|---|
| T01 | Validar componentes disponíveis | Todos | Alta | — | Componentes conferidos |
| T02 | Definir arquitetura elétrica definitiva | B | Alta | T01 | Diagrama final aprovado |
| T03 | Definir posição dos componentes | C | Alta | T01 | Layout físico definido |
| T04 | Construir base do carrinho | C | Alta | T03 | Estrutura montada |
| T05 | Fixar motores | C | Alta | T04 | Motores firmes e alinhados |
| T06 | Fixar rodas | C | Alta | T05 | Rodas girando livremente |
| T07 | Fixar suporte da bateria | C | Alta | T04 | Bateria segura |
| T08 | Fixar Arduino | C | Alta | T04 | Arduino encaixado |
| T09 | Fixar L298N | C | Alta | T04 | Ponte H encaixada |
| T10 | Fixar HC-SR04 | C | Alta | T04 | Sensor voltado para frente |
| T11 | Montar circuito de alimentação | B | Alta | T02 | Tensões conferidas |
| T12 | Conectar L298N aos motores | B | Alta | T05, T11 | Dois motores conectados |
| T13 | Conectar Arduino à L298N | B | Alta | T11 | IN1-IN4/ENA/ENB conectados |
| T14 | Testar Motor 1 | A+B | Alta | T12,T13 | Frente e ré funcionando |
| T15 | Testar Motor 2 | A+B | Alta | T12,T13 | Frente e ré funcionando |
| T16 | Programar função frente() | A | Alta | T14,T15 | Robô avança |
| T17 | Programar função re() | A | Alta | T14,T15 | Robô recua |
| T18 | Programar função esquerda() | A | Alta | T14,T15 | Robô vira à esquerda |
| T19 | Programar função direita() | A | Alta | T14,T15 | Robô vira à direita |
| T20 | Programar função parar() | A | Alta | T14,T15 | Motores param |
| T21 | Conectar HC-SR04 | B | Alta | T11 | Sensor conectado |
| T22 | Programar leitura de distância | A | Alta | T21 | Distância medida corretamente |
| T23 | Implementar parada por obstáculo | A | Alta | T20,T22 | Avanço bloqueado |
| T24 | Conectar HC-05/HC-06 | B | Alta | T11 | Comunicação serial funcionando |
| T25 | Programar leitura Bluetooth | A | Alta | T24 | Arduino recebe comandos |
| T26 | Mapear comandos Bluetooth | A | Alta | T16-T20,T25 | Todos movimentos controláveis |
| T27 | Testar perda de conexão Bluetooth | A+D | Média | T26 | Robô entra em estado seguro |
| T28 | Calibrar distância do HC-SR04 | A+D | Média | T23 | Limite seguro definido |
| T29 | Testar movimentação integrada | D | Alta | T26 | Movimentos funcionando |
| T30 | Testar detecção durante movimento | D | Alta | T23,T26 | Robô para diante de obstáculo |
| T31 | Organizar cabos | B+C | Média | T30 | Nenhum cabo interfere nas rodas |
| T32 | Testar duração da bateria | D | Média | T30 | Autonomia registrada |
| T33 | Testar robô em percurso completo | Todos | Alta | T30,T31 | Percurso concluído |
| T34 | Corrigir bugs encontrados | A+B+C | Alta | T33 | Sem falhas críticas |
| T35 | Documentar circuito | B+D | Média | T34 | Diagrama atualizado |
| T36 | Documentar software | A+D | Média | T34 | Código e comandos descritos |
| T37 | Registrar montagem física | C+D | Média | T34 | Estrutura documentada |
| T38 | Preparar demonstração final | Todos | Alta | T35-T37 | Robô pronto para apresentação |

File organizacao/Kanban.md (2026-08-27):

# Kanban – Projeto Robô Móvel

## Colunas do quadro

1. Backlog
2. A Fazer
3. Em Andamento
4. Em Teste
5. Em Correção
6. Concluído

## BACKLOG

| ID | Tarefa |
|---|---|
| T27 | Implementar e testar fail-safe do Bluetooth |
| T28 | Calibrar sensor HC-SR04 |
| T31 | Organizar cabos |
| T32 | Testar autonomia |
| T35 | Documentar circuito |
| T36 | Documentar software |
| T37 | Documentar montagem |
| T38 | Preparar apresentação |

## A FAZER

| ID | Tarefa |
|---|---|
| T01 | Validar componentes |
| T02 | Definir circuito definitivo |
| T03 | Definir layout físico |
| T04 | Construir base |
| T11 | Montar alimentação |

## EM ANDAMENTO

| Tarefa | Responsável |
|---|---|
| Planejamento do circuito | Integrante B |
| Planejamento da estrutura | Integrante C |
| Estrutura inicial do software Arduino | Integrante A |
| Plano de testes | Integrante D |

## EM TESTE

Inicialmente vazio. Conforme o desenvolvimento avançar, entram nesta coluna:

- Teste do motor esquerdo
- Teste do motor direito
- Teste do HC-SR04
- Teste do Bluetooth
- Teste de parada
- Teste integrado

## EM CORREÇÃO

Utilizada quando uma funcionalidade falha no teste.

Exemplos:
- Motor girando invertido
- Sensor instável
- Falha de comunicação Bluetooth
- Problema de alimentação
- Cabo interferindo na roda
- Comando de parada não respondendo corretamente

Depois da correção, a tarefa retorna para **Em Teste**.

## CONCLUÍDO

No início do projeto podem ser considerados concluídos:

- Requisitos definidos
- Arquitetura inicial definida
- Componentes dimensionados
- MVP definido
- Backlog criado

## Fluxo

```text
BACKLOG
   ↓
A FAZER
   ↓
EM ANDAMENTO
   ↓
EM TESTE ────────────┐
   ↓                  │
CONCLUÍDO       EM CORREÇÃO
                      │
                      └──→ EM TESTE
```

## Limite de WIP

| Coluna | Limite |
|---|---:|
| A Fazer | 6 |
| Em Andamento | 4 |
| Em Teste | 3 |
| Em Correção | 3 |
| Concluído | Sem limite |

Regra principal: cada integrante deve priorizar terminar ou desbloquear a atividade atual antes de iniciar uma nova.

## Organização sugerida em sprints

| Sprint | Objetivo | Resultado |
|---|---|---|
| Sprint 1 | Estrutura + eletrônica básica | Carrinho montado e motores ligados |
| Sprint 2 | Controle dos motores | Frente, ré, esquerda, direita e parar |
| Sprint 3 | Bluetooth | Carrinho controlado pelo celular |
| Sprint 4 | Sensor ultrassônico | Detecção e parada automática |
| Sprint 5 | Integração | MVP concluído |
| Sprint 6 | Testes e melhorias | Sistema estabilizado |
| Sprint 7 | Acabamento e documentação | Projeto concluído |

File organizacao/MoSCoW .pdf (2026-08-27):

MoSCoW – Robô
A classificação MoSCoW define quais funcionalidades são essenciais para o MVP e quais podem ser implementadas posteriormente.

MUST HAVE – Obrigatório
Funcionalidade | Justificativa
Controle pelo Arduino | Controlador central do robô
Alimentação por bateria | Necessária para mobilidade
Controle dos motores pela L298N Necessário para movimentação
Movimento para frente | Função básica
Movimento para trás | Função básica
Virar para esquerda | Necessário para navegação
Virar para direita | Necessário para navegação
Parar | Requisito fundamental de segurança
Comunicação Bluetooth | Permite controle remoto
Sensor HC-SR04 | Permite detectar obstáculos
Parada automática | Evita colisões
Estrutura para fixação | Mantém os componentes seguros
GND comum | Necessário para funcionamento elétrico correto

SHOULD HAVE – Importante

Funcionalidade | Justificativa
Controle de velocidade por PWM | Melhora a dirigibilidade
Distância mínima configurável | Facilita calibração
Feedback de estado via Bluetooth | Informa o estado atual ao usuário
Organização dos cabos | Aumenta confiabilidade
Tratamento de perda do Bluetooth | Melhora segurança
Timeout de comando | Evita movimento indefinido
Indicador de bateria | Facilita operação

COULD HAVE – Desejável
Funcionalidade | Justificativa
Modo automático | Permite navegação sem controle manual
Desvio automático de obstáculos | Evolução da detecção
Controle de velocidade pelo celular Melhora experiência do usuário
LEDs indicadores | Oferecem feedback visual
Buzzer | Oferece feedback sonoro
Telemetria de distância | Permite visualizar distância no celular
Aplicativo próprio | Melhora interface de controle
Registro de comandos | Facilita diagnóstico

WON'T HAVE – Fora do escopo inicial
- Navegação por GPS
- Câmera
- Reconhecimento de imagem
- Inteligência Artificial
- Mapeamento do ambiente
- Controle pela internet
- Navegação autônoma avançada
- SLAM

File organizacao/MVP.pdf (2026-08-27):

MVP do Projeto – Robô Móvel
Objetivo do projeto
Construir um robô de duas rodas motorizadas utilizando Arduino Uno, Ponte H L298N, dois motores DC, sensor ultrassônico HC-SR04, módulo Bluetooth HC-05/HC-06 e bateria de 7,4 V.
O robô deverá ser capaz de se movimentar para frente, para trás, virar para esquerda e direita, parar, receber comandos via Bluetooth e interromper automaticamente o movimento ao detectar um obstáculo.
Quando o projeto estará minimamente funcional?
O MVP estará pronto quando o robô conseguir se movimentar de forma controlada e segura, mesmo não possuindo acabamento final ou organização definitiva dos cabos. Critérios para considerar o MVP pronto
Requisito | Critério de aceite
Arduino operacional | Programa carregado e executando corretamente
Ponte H L298N | Controla os dois motores
Movimento para frente Os dois motores movimentam o robô para frente
Movimento para trás | Os dois motores movimentam o robô para trás
Curva esquerda | O robô consegue virar para a esquerda
Curva direita | O robô consegue virar para a direita
Parada | Os motores podem ser interrompidos imediatamente
Bluetooth | O celular consegue enviar comandos ao Arduino
HC-SR04 | O sensor mede corretamente a distância
Segurança | O robô interrompe o avanço ao detectar obstáculo
Alimentação | O sistema opera usando a bateria de 7,4 V

Resultado esperado do MVP
O usuário deve conseguir colocar o carrinho no chão, conectar o celular via Bluetooth e executar os comandos de frente, ré, esquerda, direita e parar. Caso um obstáculo seja detectado à frente, o robô deve impedir o avanço.
Quando o projeto estará concluído?
O projeto será considerado concluído quando, além de cumprir os requisitos do MVP, estiver mecanicamente organizado, testado e documentado.
Quando estará concluído?

Área | Condição de conclusão
Mecânica | Todos os componentes fixados corretamente
Eletrônica | Ligações definitivas e sem conexões soltas
Alimentação | Bateria e Arduino alimentados de maneira adequada
Software | Código organizado, funcional e comentado
Bluetooth | Comunicação estável com o celular
Sensor | Detecção de obstáculos validada
Movimento | Frente, ré e curvas funcionando de forma consistente
Segurança | Obstáculo tem prioridade sobre comando de avanço
Estrutura | Nenhum componente interfere nas rodas
Testes | Testes individuais e integrados concluídos
Documentação Circuito, código, backlog e funcionamento documentados Demonstração Robô completa um percurso de teste sem falhas críticas

Checkpoints do Projeto
- MVP: robô funcional, controlável e com parada por obstáculo.
- Projeto concluído: robô funcional, confiável, organizado, testado e documentado.

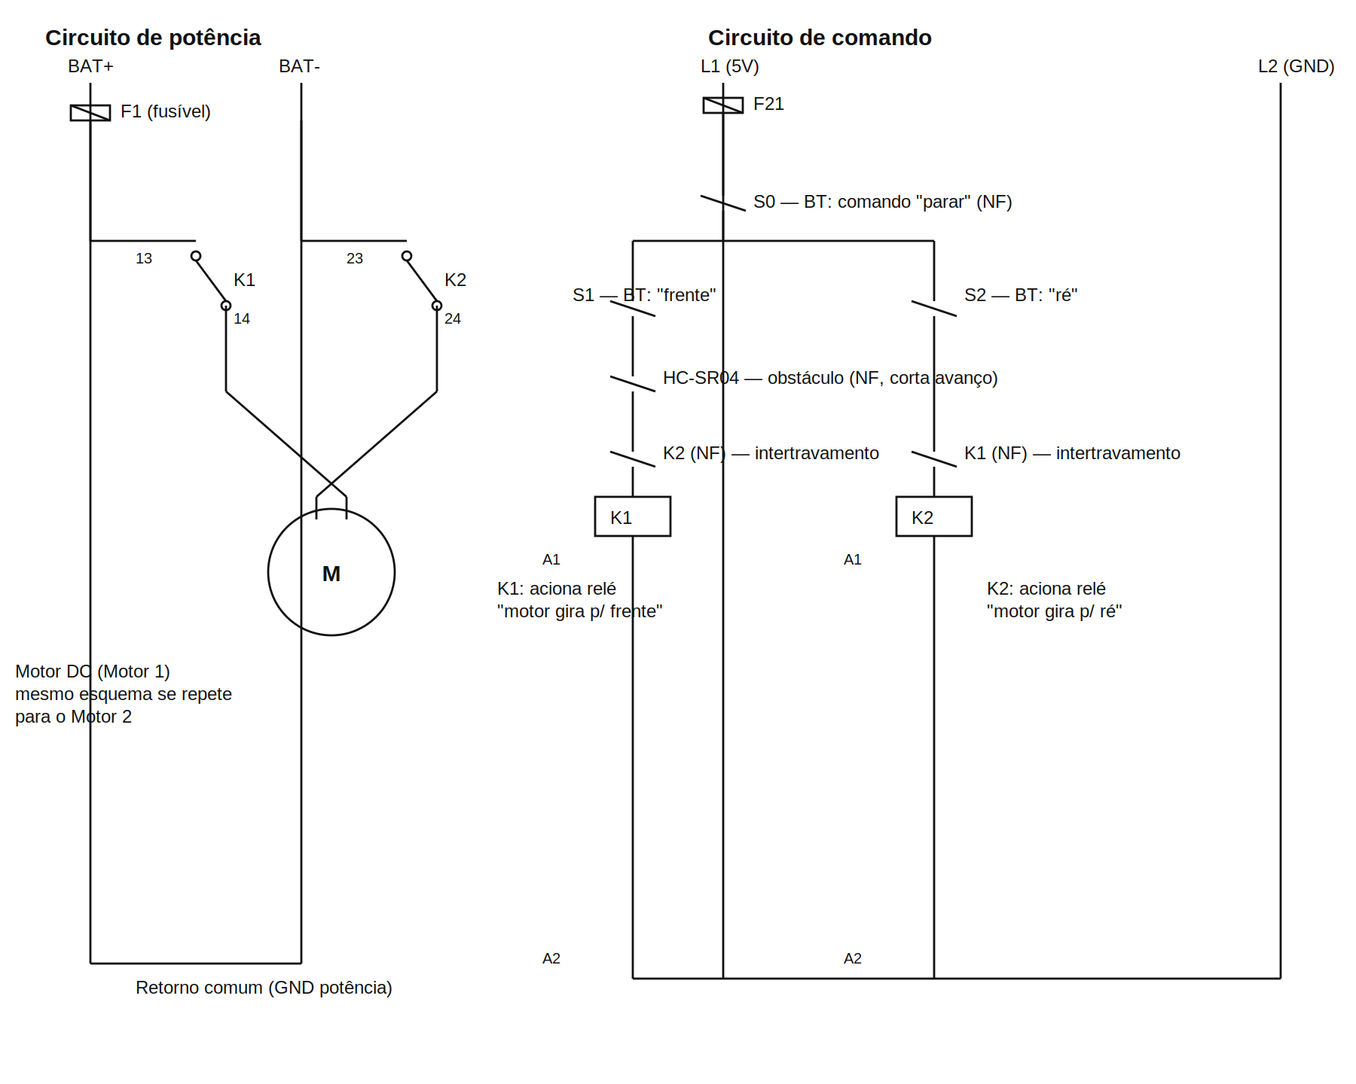
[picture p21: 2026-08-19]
img/diagrama-eletrico.png

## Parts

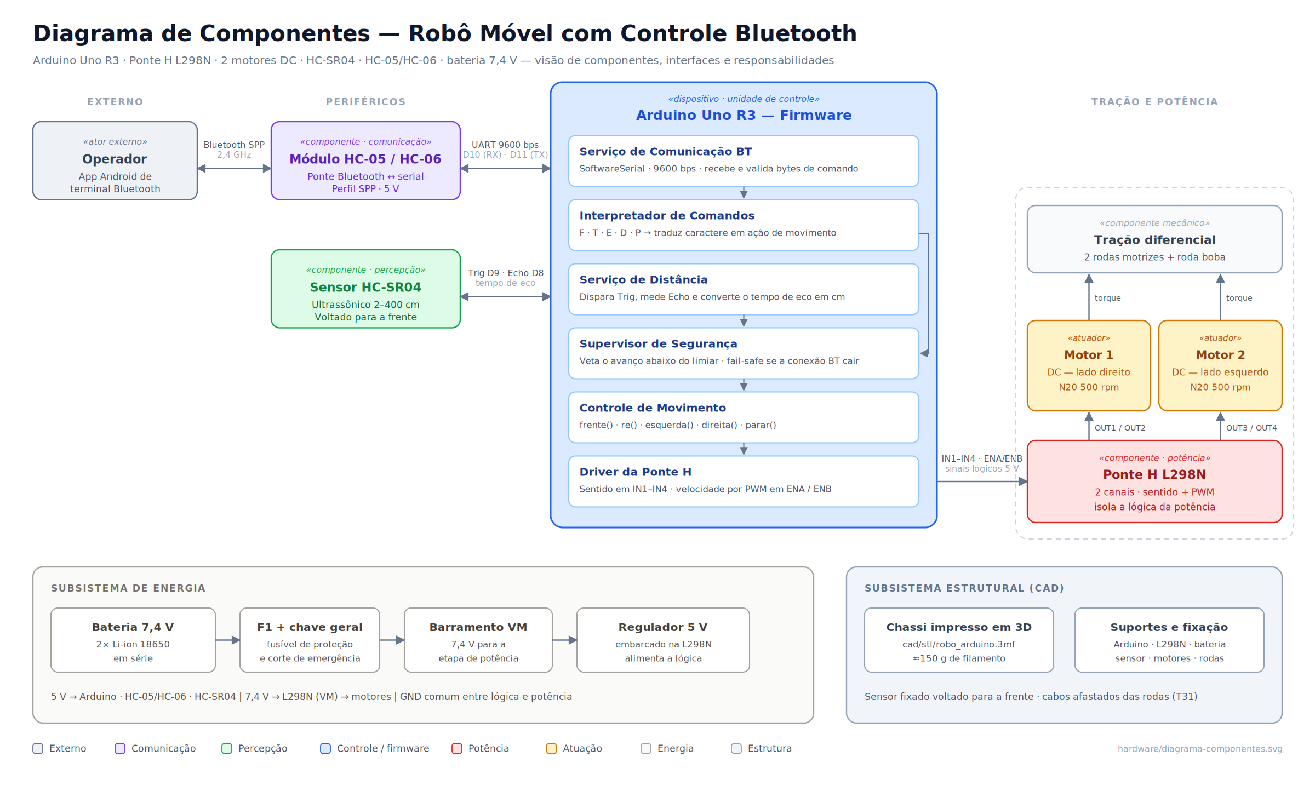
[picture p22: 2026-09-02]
hardware/diagrama-componentes.png

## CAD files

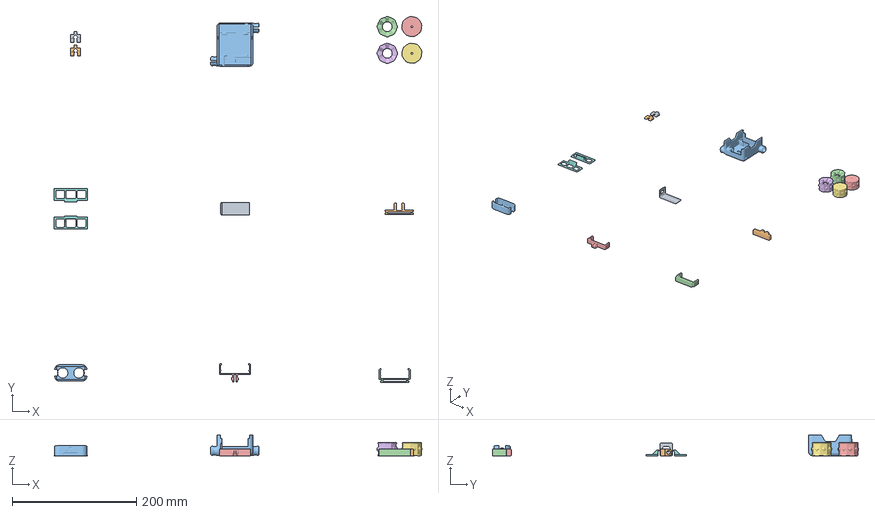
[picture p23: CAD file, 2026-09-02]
cad/stl/robo_arduino.3mf
591.7 x 588.6 x 33.0 mm
mechanical_track.stl x 2
chassis_-SL.stl
slave_wheel_SL.stl x 2
master_wheel.stl x 2
holding_board__9V.stl
ir_sensor_b.stl
connector_a.stl
ultrasonic_1.stl
ultrasonic_2b_V2.stl
ultrasonic_2a_V2.stl

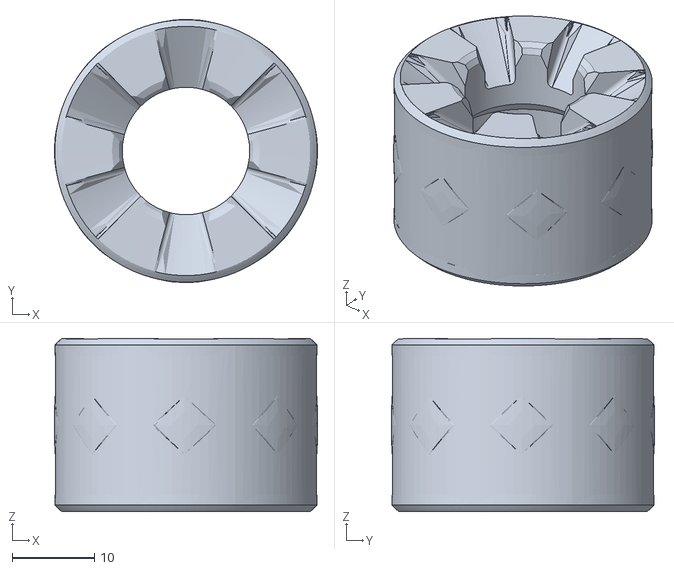
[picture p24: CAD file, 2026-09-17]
cad/stl/rodas/roda_livre_lisa.stl
32.0 x 32.0 x 21.0

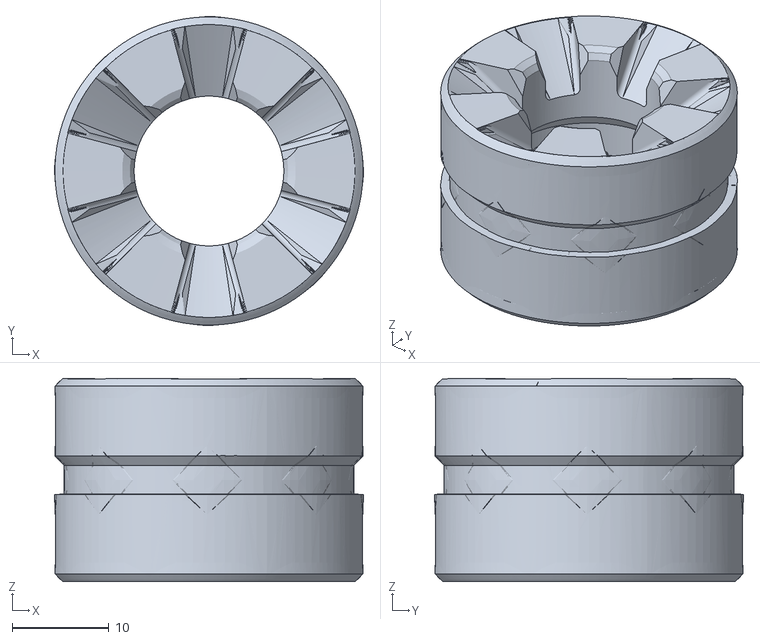
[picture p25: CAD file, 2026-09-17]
cad/stl/rodas/roda_livre_canal.stl
32.0 x 32.0 x 21.0

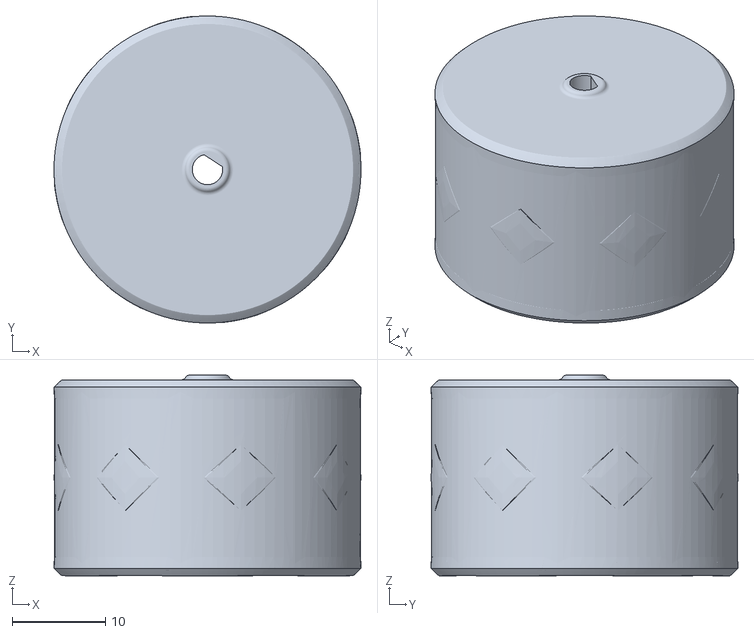
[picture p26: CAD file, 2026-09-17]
cad/stl/rodas/roda_motor_lisa.stl
32.9 x 32.9 x 21.5

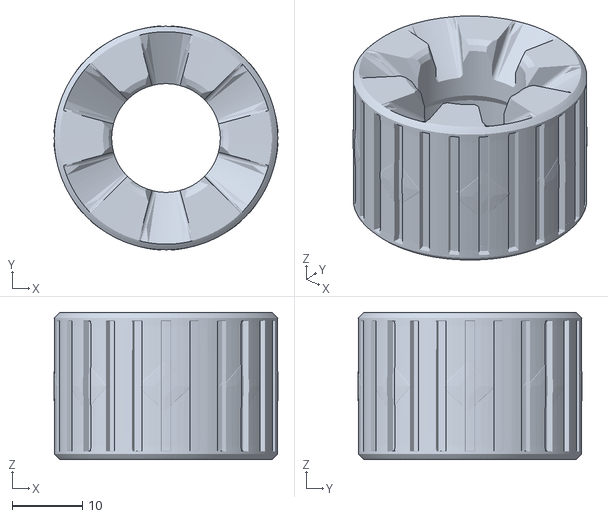
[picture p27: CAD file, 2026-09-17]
cad/stl/rodas/roda_livre_ranhurada.stl
32.0 x 32.0 x 21.0

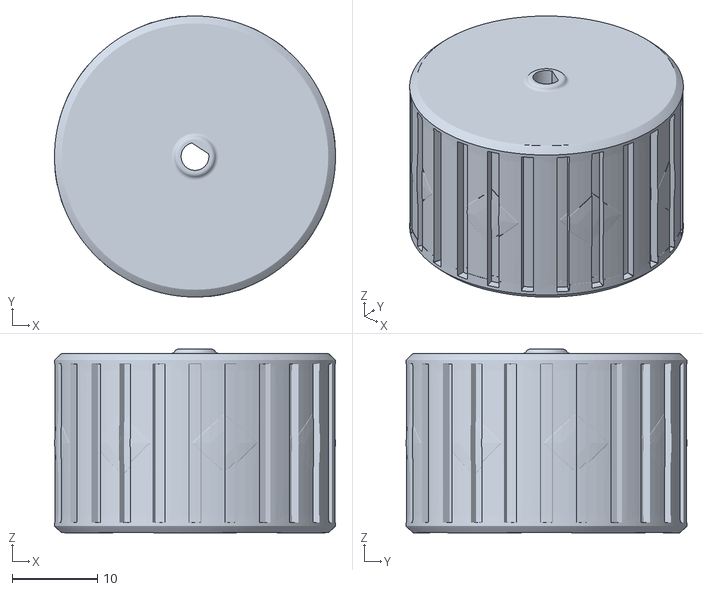
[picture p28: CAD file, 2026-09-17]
cad/stl/rodas/roda_motor_ranhurada.stl
32.9 x 32.9 x 21.5

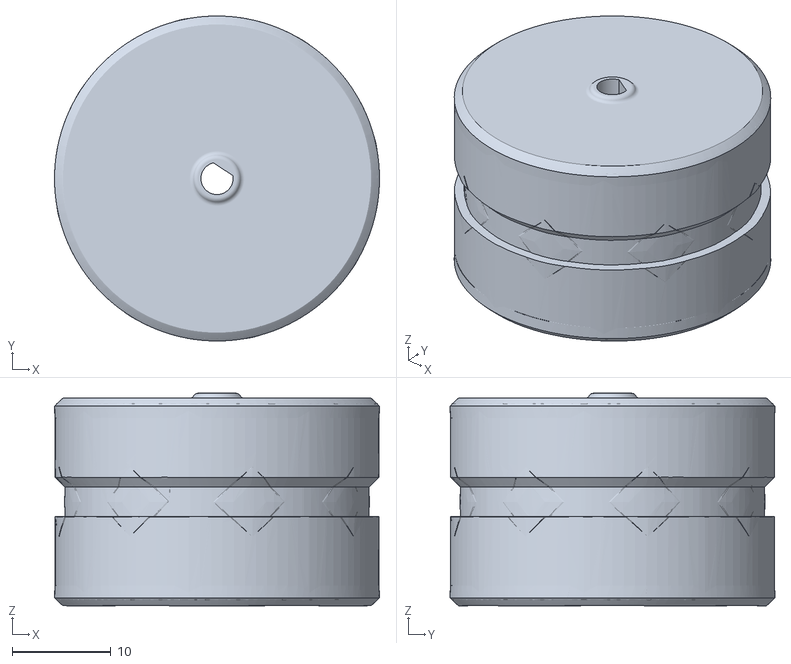
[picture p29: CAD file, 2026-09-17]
cad/stl/rodas/roda_motor_canal.stl
32.9 x 32.9 x 21.5

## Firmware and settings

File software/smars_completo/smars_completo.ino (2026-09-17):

/*
  SMARS - firmware completo: Bluetooth + sensor ultrassônico + modo autônomo (um único upload)

  Modos:
    MANUAL (padrão): comandos do app pelo Bluetooth. O sensor funciona como SEGURANÇA: se houver
                     obstáculo a menos de DIST_PARAR, os comandos de avanço (F/G/I) são bloqueados e o
                     carrinho para; ré e giros continuam liberados. Liberou o caminho, o avanço volta.
    AUTÔNOMO:        o carrinho anda sozinho desviando de obstáculos (mesma lógica do smars_desvio v3).

  Comandos Bluetooth (app "Arduino Bluetooth RC Car" ou terminal serial):
    F/B/L/R  frente / ré / esquerda / direita      S  parar (também sai do modo autônomo)
    G/I      frente-esquerda / frente-direita      H/J  ré-esquerda / ré-direita
    0-9, q   velocidade (slider do app)
    X        liga o modo autônomo                  x  desliga o modo autônomo

  Hardware: Arduino Uno + shield L293D (AFMotor) + 2x N20 em M1/M2 + HC-SR04 em A0/A1 +
            HC-05 em D9/D10 (pinos dos conectores de servo do shield) + bateria 9 V no shield.
*/

#include <AFMotor.h>
#include <SoftwareSerial.h>

// ---------------- Hardware ----------------
SoftwareSerial bt(9, 10);      // RX, TX
AF_DCMotor motorE(1);          // esquerdo em M1
AF_DCMotor motorD(2);          // direito em M2
const int PINO_TRIG = A0;
const int PINO_ECHO = A1;

const int VEL_MAX_E = 255;     // teto por motor: abaixe o mais forte se o carrinho puxa pra um lado
const int VEL_MAX_D = 255;

// ---------------- Parâmetros (ajuste aqui) ----------------
const int DIST_PARAR   = 20;   // cm: obstáculo -> bloqueia avanço (manual) / desvia (autônomo)
const int DIST_REDUZIR = 45;   // cm: autônomo desacelera daqui até DIST_PARAR
const int DIST_LIVRE   = 40;   // cm: mínimo pra considerar a direção livre ao girar

const int VEL_CRUZEIRO = 220;  // autônomo: velocidade normal
const int VEL_MINIMA   = 130;  // autônomo: perto de obstáculo
const int VEL_MANOBRA  = 255;  // manobras
const int VEL_CURVA_INTERNA = 90;   // manual: roda de dentro nas diagonais

const int T_RE_MS = 400, T_RE_ARCO_MS = 700, T_GIRO_MIN_MS = 250, T_MARGEM_MS = 200, T_MEIA_VOLTA_MS = 1200, T_PAUSA_MS = 120;
const unsigned long T_GIRO_MAX_MS = 2500;
const int LEITURAS_LIVRES = 3;
const unsigned long INTERVALO_PING_MS = 60;
const int MAX_DESVIOS_SEGUIDOS = 3;
const unsigned long JANELA_PRESO_MS = 6000;
const bool TELEMETRIA = false; // true: envia a distância pelo Bluetooth a cada 500 ms (use com app de terminal)

// ---------------- Estado ----------------
bool modoAuto = false;
char ultimoComando = 'S';
int vel = 255;
int leituras[3] = {400, 400, 400};
byte idxLeitura = 0;
int distancia = 400;
unsigned long ultimoPing = 0, ultimoLog = 0;
bool ladoDireita = true;
byte desviosRecentes = 0;
unsigned long inicioJanela = 0;

// ---------------- Motores ----------------
void aplicar(int e, int d, uint8_t dirE, uint8_t dirD) {
  motorE.setSpeed(map(constrain(e, 0, 255), 0, 255, 0, VEL_MAX_E));
  motorD.setSpeed(map(constrain(d, 0, 255), 0, 255, 0, VEL_MAX_D));
  motorE.run(dirE); motorD.run(dirD);
}
void frente(int v) { aplicar(v, v, FORWARD, FORWARD); }
void re(int v)     { aplicar(v, v, BACKWARD, BACKWARD); }
void parar()       { aplicar(0, 0, RELEASE, RELEASE); }
void girar(bool direita, int v) { aplicar(v, v, direita ? FORWARD : BACKWARD, direita ? BACKWARD : FORWARD); }
void reArco(bool narizDireita, int v) { if (narizDireita) aplicar(v / 3, v, BACKWARD, BACKWARD); else aplicar(v, v / 3, BACKWARD, BACKWARD); }

// ---------------- Sensor ----------------
int lerCrua() {
  digitalWrite(PINO_TRIG, LOW);  delayMicroseconds(2);
  digitalWrite(PINO_TRIG, HIGH); delayMicroseconds(10);
  digitalWrite(PINO_TRIG, LOW);
  unsigned long dur = pulseIn(PINO_ECHO, HIGH, 25000UL);
  if (dur == 0) return 400;
  return constrain((int)(dur / 58), 2, 400);
}
int mediana3(int a, int b, int c) {
  if (a > b) { int t = a; a = b; b = t; }
  if (b > c) { int t = b; b = c; c = t; }
  if (a > b) { int t = a; a = b; b = t; }
  return b;
}
void atualizarDistancia() {
  if (millis() - ultimoPing < INTERVALO_PING_MS) return;
  ultimoPing = millis();
  leituras[idxLeitura] = lerCrua();
  idxLeitura = (idxLeitura + 1) % 3;
  distancia = mediana3(leituras[0], leituras[1], leituras[2]);
}
int medirParado() {
  parar(); delay(T_PAUSA_MS);
  int a = lerCrua(); delay(40);
  int b = lerCrua(); delay(40);
  int c = lerCrua();
  int m = mediana3(a, b, c);
  leituras[0] = leituras[1] = leituras[2] = m;
  distancia = m;
  return m;
}

// ---------------- Manobras do modo autônomo ----------------
bool girarAteLivre(bool direita, unsigned long maxMs) {
  girar(direita, VEL_MANOBRA);
  unsigned long t0 = millis(); int livres = 0;
  while (millis() - t0 < maxMs) {
    delay(INTERVALO_PING_MS);
    int d = lerCrua();
    livres = (d >= DIST_LIVRE) ? livres + 1 : 0;
    if (livres >= LEITURAS_LIVRES && millis() - t0 >= (unsigned long)T_GIRO_MIN_MS) { delay(T_MARGEM_MS); parar(); return true; }
  }
  parar(); return false;
}
bool registrarDesvio() {
  unsigned long agora = millis();
  if (agora - inicioJanela > JANELA_PRESO_MS) { inicioJanela = agora; desviosRecentes = 0; }
  desviosRecentes++;
  if (desviosRecentes >= MAX_DESVIOS_SEGUIDOS) { desviosRecentes = 0; inicioJanela = agora; return true; }
  return false;
}
void desviar() {
  bool preso = registrarDesvio();
  Serial.print(F("Obstaculo a ")); Serial.print(distancia); Serial.println(preso ? F(" cm - preso, fuga") : F(" cm"));
  parar(); delay(T_PAUSA_MS);
  if (preso) { ladoDireita = !ladoDireita; reArco(ladoDireita, VEL_MANOBRA); delay(2 * T_RE_ARCO_MS); }
  else       { re(VEL_MANOBRA); delay(T_RE_MS); }
  if (girarAteLivre(ladoDireita, T_GIRO_MAX_MS)) { medirParado(); return; }
  reArco(!ladoDireita, VEL_MANOBRA); delay(T_RE_ARCO_MS);
  if (girarAteLivre(!ladoDireita, T_GIRO_MAX_MS)) { ladoDireita = !ladoDireita; medirParado(); return; }
  girar(ladoDireita, VEL_MANOBRA); delay(T_MEIA_VOLTA_MS);
  medirParado();
}
void passoAutonomo() {
  if (distancia <= DIST_PARAR) { desviar(); return; }
  int v = VEL_CRUZEIRO;
  if (distancia < DIST_REDUZIR) v = map(distancia, DIST_PARAR, DIST_REDUZIR, VEL_MINIMA, VEL_CRUZEIRO);
  frente(v);
}

// ---------------- Modo manual ----------------
bool comandoAvanca(char c) { return c == 'F' || c == 'G' || c == 'I'; }

void executarManual() {
  char c = ultimoComando;
  if (comandoAvanca(c) && distancia <= DIST_PARAR) { parar(); return; }   // segurança: obstáculo veta o avanço
  int vi = vel * VEL_CURVA_INTERNA / 255;
  switch (c) {
    case 'F': frente(vel); break;
    case 'B': re(vel); break;
    case 'L': girar(false, vel); break;
    case 'R': girar(true, vel); break;
    case 'G': aplicar(vi,  vel, FORWARD,  FORWARD);  break;
    case 'I': aplicar(vel, vi,  FORWARD,  FORWARD);  break;
    case 'H': aplicar(vi,  vel, BACKWARD, BACKWARD); break;
    case 'J': aplicar(vel, vi,  BACKWARD, BACKWARD); break;
    default:  parar(); break;
  }
}

void tratarBluetooth() {
  while (bt.available()) {
    char c = bt.read();
    if (c >= '0' && c <= '9') { vel = map(c - '0', 0, 9, 25, 230); continue; }
    if (c == 'q' || c == 'Q') { vel = 255; continue; }
    if (c == 'X') { modoAuto = true;  Serial.println(F("modo AUTONOMO")); medirParado(); continue; }
    if (c == 'x') { modoAuto = false; ultimoComando = 'S'; parar(); Serial.println(F("modo MANUAL")); continue; }
    char u = toupper(c);
    if (u == 'S' || u == 'D') { modoAuto = false; ultimoComando = 'S'; parar(); continue; }
    if (u == 'F' || u == 'B' || u == 'L' || u == 'R' || u == 'G' || u == 'I' || u == 'H' || u == 'J') {
      modoAuto = false; ultimoComando = u;
      Serial.print(F("cmd ")); Serial.println(u);
    }
  }
}

// ---------------- Arduino ----------------
void setup() {
  Serial.begin(9600);
  bt.begin(9600);
  pinMode(PINO_TRIG, OUTPUT);
  pinMode(PINO_ECHO, INPUT);
  digitalWrite(PINO_TRIG, LOW);
  parar();
  Serial.println(F("SMARS completo: manual (Bluetooth) + seguranca + autonomo (X/x)"));
}

void loop() {
  tratarBluetooth();
  atualizarDistancia();

  if (modoAuto) passoAutonomo();
  else          executarManual();

  if (millis() - ultimoLog >= 500) {
    ultimoLog = millis();
    Serial.print(modoAuto ? F("[AUTO] ") : F("[MANUAL] ")); Serial.print(distancia); Serial.println(F(" cm"));
    if (TELEMETRIA) { bt.print(distancia); bt.println(F(" cm")); }
  }
}

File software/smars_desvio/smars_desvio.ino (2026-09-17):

/*
  SMARS - desvio de obstáculos com HC-SR04 (sensor fixo, sem servo) - v3

  Ideia central: o carrinho NUNCA volta a andar pra frente "no escuro". Depois de um obstáculo
  ele gira e continua girando ATÉ O SENSOR VER CAMINHO LIVRE (várias leituras seguidas), com uma
  margem extra. Não depende de virar "exatamente 45°" - se girar devagar, só demora mais.

  Sequência ao encontrar obstáculo:
    1. para, dá uma ré curta
    2. gira pro lado preferido até ver caminho livre  -> achou? segue
    3. não achou: ré em arco pro outro lado (tira o nariz da parede) e gira pro outro lado até livre
    4. não achou: meia-volta e segue
  Batidas seguidas mantêm o MESMO lado (se virou pra direita e bateu de novo, a parede está à
  esquerda: virar mais pra direita). 3 desvios em 6 s = preso: ré em arco longa e troca de lado.

  Mecânica: girar no lugar obriga as rodas LIVRES a deslizar de lado. Elástico só nas rodas do
  motor; as livres têm que ficar lisas, senão o carrinho não gira.
*/

#include <AFMotor.h>

// ---------------- Motores ----------------
AF_DCMotor motorE(1);   // esquerdo em M1
AF_DCMotor motorD(2);   // direito em M2

const int VEL_MAX_E = 255;   // teto por motor (0-255): abaixe o mais forte se ele puxa pra um lado
const int VEL_MAX_D = 255;

// ---------------- Sensor HC-SR04 ----------------
const int PINO_TRIG = A0;
const int PINO_ECHO = A1;

// ---------------- Comportamento (ajuste aqui) ----------------
const int DIST_PARAR   = 20;    // cm: abaixo disso para e desvia
const int DIST_REDUZIR = 45;    // cm: daqui até PARAR vai desacelerando
const int DIST_LIVRE   = 40;    // cm: mínimo pra considerar a direção "livre" ao girar

const int VEL_CRUZEIRO = 220;   // velocidade normal
const int VEL_MINIMA   = 130;   // perto de obstáculo (abaixo disso o TT nem sai do lugar)
const int VEL_MANOBRA  = 255;   // manobras sempre com força total (precisa vencer o atrito lateral)

const int T_RE_MS           = 400;    // ré reta antes de girar
const int T_RE_ARCO_MS      = 700;    // ré em arco (quando o primeiro lado não abre)
const int T_GIRO_MIN_MS     = 250;    // gira pelo menos isso antes de aceitar "livre"
const int T_MARGEM_MS       = 200;    // continua girando esse tanto depois de ver livre (afasta da borda)
const unsigned long T_GIRO_MAX_MS = 2500;   // desiste de procurar pra esse lado depois disso
const int T_MEIA_VOLTA_MS   = 1200;   // último recurso (CALIBRE: tempo pra ~180°)
const int LEITURAS_LIVRES   = 3;      // leituras seguidas >= DIST_LIVRE pra aceitar
const int T_PAUSA_MS        = 120;

const unsigned long INTERVALO_PING_MS = 60;
const int MAX_DESVIOS_SEGUIDOS = 3;
const unsigned long JANELA_PRESO_MS = 6000;

// ---------------- Estado ----------------
int leituras[3] = {400, 400, 400};
byte idxLeitura = 0;
int distancia = 400;
unsigned long ultimoPing = 0, ultimoLog = 0;
bool ladoDireita = true;          // lado preferido pra virar (mantém entre batidas seguidas)
byte desviosRecentes = 0;
unsigned long inicioJanela = 0;

// ---------------- Motores ----------------
void velocidade(int e, int d) {
  motorE.setSpeed(map(constrain(e, 0, 255), 0, 255, 0, VEL_MAX_E));
  motorD.setSpeed(map(constrain(d, 0, 255), 0, 255, 0, VEL_MAX_D));
}
void frente(int v)   { velocidade(v, v); motorE.run(FORWARD);  motorD.run(FORWARD);  }
void re(int v)       { velocidade(v, v); motorE.run(BACKWARD); motorD.run(BACKWARD); }
void parar()         { motorE.run(RELEASE); motorD.run(RELEASE); }

// gira no lugar: direita = sentido horário visto de cima (esquerdo pra frente, direito pra trás)
void girar(bool direita, int v) {
  velocidade(v, v);
  motorE.run(direita ? FORWARD : BACKWARD);
  motorD.run(direita ? BACKWARD : FORWARD);
}
// ré em arco: dá ré girando o nariz pro lado pedido (a roda desse lado anda mais)
void reArco(bool narizDireita, int v) {
  if (narizDireita) velocidade(v / 3, v); else velocidade(v, v / 3);
  motorE.run(BACKWARD); motorD.run(BACKWARD);
}

// ---------------- Sensor ----------------
int lerCrua() {
  digitalWrite(PINO_TRIG, LOW);  delayMicroseconds(2);
  digitalWrite(PINO_TRIG, HIGH); delayMicroseconds(10);
  digitalWrite(PINO_TRIG, LOW);
  unsigned long dur = pulseIn(PINO_ECHO, HIGH, 25000UL);   // timeout 25 ms ~ 4 m
  if (dur == 0) return 400;                                // sem eco = livre
  return constrain((int)(dur / 58), 2, 400);
}
int mediana3(int a, int b, int c) {
  if (a > b) { int t = a; a = b; b = t; }
  if (b > c) { int t = b; b = c; c = t; }
  if (a > b) { int t = a; a = b; b = t; }
  return b;
}
void atualizarDistancia() {              // um ping a cada 60 ms, mediana das 3 últimas
  if (millis() - ultimoPing < INTERVALO_PING_MS) return;
  ultimoPing = millis();
  leituras[idxLeitura] = lerCrua();
  idxLeitura = (idxLeitura + 1) % 3;
  distancia = mediana3(leituras[0], leituras[1], leituras[2]);
}
int medirParado() {                      // 3 leituras novas parado + zera o filtro
  parar();
  delay(T_PAUSA_MS);
  int a = lerCrua(); delay(40);
  int b = lerCrua(); delay(40);
  int c = lerCrua();
  int m = mediana3(a, b, c);
  leituras[0] = leituras[1] = leituras[2] = m;
  distancia = m;
  return m;
}

// ---------------- Manobras ----------------
// Gira pro lado pedido até o sensor ver caminho livre. true = achou.
bool girarAteLivre(bool direita, unsigned long maxMs) {
  Serial.print(F("  girando p/ ")); Serial.print(direita ? F("direita") : F("esquerda")); Serial.print(F("... "));
  girar(direita, VEL_MANOBRA);
  unsigned long t0 = millis();
  int livres = 0;
  while (millis() - t0 < maxMs) {
    delay(INTERVALO_PING_MS);
    int d = lerCrua();
    livres = (d >= DIST_LIVRE) ? livres + 1 : 0;
    if (livres >= LEITURAS_LIVRES && millis() - t0 >= (unsigned long)T_GIRO_MIN_MS) {
      delay(T_MARGEM_MS);              // um pouco além, pra não raspar na quina do obstáculo
      parar();
      Serial.print(F("livre em ")); Serial.print(millis() - t0); Serial.println(F(" ms"));
      return true;
    }
  }
  parar();
  Serial.println(F("nada livre"));
  return false;
}

bool registrarDesvio() {                 // true = 3 desvios em 6 s (preso)
  unsigned long agora = millis();
  if (agora - inicioJanela > JANELA_PRESO_MS) { inicioJanela = agora; desviosRecentes = 0; }
  desviosRecentes++;
  if (desviosRecentes >= MAX_DESVIOS_SEGUIDOS) { desviosRecentes = 0; inicioJanela = agora; return true; }
  return false;
}
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

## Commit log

2026-09-02 entrega 16
    [robo_arduino.3mf]
2026-09-17 cad: rodas redesenhadas (v1 lisa, v2 ranhurada, v4 canal p/ elastico) e scripts de geracao
    Esteiras do SMARS descartadas apos travarem o motor. Rodas regeneradas a partir
    do STL original preservando o encaixe do N20 e do eixo; motora O33 x livre O32
    para garantir contato com o chao; canal com rampa de 45 graus imprime sem suporte.
    [roda_livre_canal.stl, roda_livre_lisa.stl, roda_livre_ranhurada.stl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]
2026-09-17 software: firmware v2/v3 de desvio, bluetooth v2 e firmware unificado
    - desvio: leitura com timeout e mediana, gira ate o sensor ver caminho livre,
    re em arco, meia-volta e fuga quando preso
    - bluetooth: available(), slider de velocidade, diagonais, compensacao por motor
    - smars_completo: modo manual com bloqueio de avanco por obstaculo + modo autonomo
    - historico/: versoes iniciais v1 com os problemas anotados
    [smars_bluetooth.ino, smars_completo.ino, smars_desvio.ino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]
2026-09-17 img/hardware: fotos da montagem, placas de impressao, renders das rodas e pinagem final
    Pinagem real construida: shield L293D, HC-SR04 em A0/A1, HC-05 em D9/D10,
    bateria 9 V no EXT_PWR. Diagrama L298N anterior mantido como historico.
2026-09-17 docs: README final do Check Point 1
    Linha do tempo, decisoes planejado x construido, evolucao das rodas e do
    software, testes, instrucoes de uso, custos e link do video.
